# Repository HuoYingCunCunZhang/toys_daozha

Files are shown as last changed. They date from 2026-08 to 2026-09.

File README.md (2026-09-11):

# 道闸玩具（toys_daozha）

道闸（barrier gate）造型的儿童玩具。**语音是核心**：ESP32-S3 + ESP-SR 离线识别，只认三条命令——起杆 / 落杆 / 复位。配一个 ESP-NOW 直连的三键遥控器。目标玩家 6~10 岁。

---

## 当前进度（2026-09-11）

| 阶段 | 状态 |
|---|---|
| 需求冻结 | ✅ |
| 电路方案 | ✅ |
| 原理图连线 + 网表校验 | ✅ **24 条网络全通**（删了 `M_FAULT`）|
| 元器件选型与实测尺寸 | ✅ 全部转 📄 |
| 改 EDA 封装（4 项 + U1 行距） | ✅ **全部完成** |
| **PCB 布局** | ✅ **已定稿并校验**（22 元件 / 119 焊盘 / 0 重叠 / 占用率 51%）|
| **PCB 布线** | ✅ **完成，DRC 零错误**（105 段 / 0 过孔 / 两面 GND 覆铜）|
| **CAD 结构件** | ✅ **v3.3**——12 个零件，闸杆改 +Y，STL/3MF 全部导出 |
| 装配手册 + 采购/紧固件清单 | ✅ 已对齐 v3.3，含 9 颗贴片件的手焊步骤 |
| **固件 · 骨架** | ✅ **主机 + 遥控器工程已建**，见 [`firmware/`](firmware/README.md) |
| **固件 · 主机实机** | ✅ **按键长按走/松手停 实测通过**（09-11）。控制模型已换：限位只做"碰到就停"，无回零、无 T 标定、无防砸 |
| **固件 · 遥控器实机** | 🔴 **三个键没按就全读 0**，疑轻触开关脚对与封装不符，待万用表量（见 firmware/README） |
| **固件 · 语音（M5）** | ✅ **已实现**（ESP-SR：WakeNet9「你好小智」+ MultiNet7 中文三词），识别率待实测 |
| 遥控器 · BOM 与尺寸 | ✅ 定案（无状态灯 / 无电量检测 / 外壳可放大）|
| 遥控器 · 原理图 | ✅ **已建工程并连线，8 条网络几何校验全通过**（含 2 条阳性对照）|
| 遥控器 · PCB | ✅ **完成，DRC 零错误**（板 **57×33**，8 条网络分层连通已验证）|
| 遥控器 · 外壳 | ✅ **完成**（**63 × 40 × 26**）——上盖只留抬杆/落杆两个按键孔，加四条板压条 |

> 🔴 **板子和底座已放大**：承载底板 100×55 → **120 × 65**，底座 163×63×25 → **183 × 73 × 25**。
> 原因：U4 实测 **37mm** 长（当初定 100×55 时按 SX1308 的 23mm 算），37mm 连续跨度在小板上差 3.2mm 放不下。
> 放大后占用率 71% → **51%**，最小间距 ≥0.87mm。坐标见 [机械约束 §七之二](道闸玩具_底板机械约束_v1.md)。
>
> 🔴 **U1 DevKit 封装的排针行距是错的，已修正**：系统库给 22.86mm，卖家尺寸图是 **25.4mm**。照原样打样 DevKit 插不进去。
>
> 🔴 **闸体从 x=25 挪到了 x=55**（CAD 解冻时发现）：PCB 定稿的起杆按键在 x=+20，而闸体原来占 x=2…48，**整颗按键被闸体盖住**。按"结构让路给 PCB"挪的是闸体。

---

## 文档索引（按使用顺序）

| # | 文档 | 作用 |
|---|---|---|
| 1 | [需求规格说明书 v2](道闸玩具_需求规格说明书_v2.md) | 要做什么、不做什么 |
| 2 | [电路与结构设计方案 v2.5](道闸玩具_电路与结构设计方案_v2.md) | 总体方案、GPIO 分配、状态机 |
| 3 | **[元器件尺寸基准 v1](道闸玩具_元器件尺寸基准_v1.md)** | **所有物理尺寸的唯一事实源。CAD 和 PCB 都只能引用它** |
| 4 | [底板网表基准 v2](道闸玩具_底板网表基准_v2.md) | 25 条网络的连接关系、防砸方案 |
| 5 | [底板选型锁定 v1](道闸玩具_底板选型锁定_v1.md) | 器件型号与 EDA device uuid |
| 6 | **[底板机械约束 v2](道闸玩具_底板机械约束_v1.md)** | **PCB 布局必读**：外形、安装孔、净空、钉死的器件位置、要改的封装 |
| 7 | **[采购与装配清单 v1](道闸玩具_采购与装配清单_v1.md)** | **买什么、谁来焊、按什么顺序装**（新手向）|
| 8 | [紧固件清单 v1](道闸玩具_紧固件清单_v1.md) | 27 颗螺丝的规格与长度依据 |
| 9 | [cad/README](cad/README.md) | CAD 源码说明、建模踩过的坑 |
| 10 | **[firmware/README](firmware/README.md)** | **固件工程说明**：环境、编译烧录、引脚、状态机、上电前必查的三件事 |

---

## 下一步该做什么（给接手的 agent）

### 任务 1 · 改 EDA 封装 ✅ **已完成**

见 [机械约束 §七](道闸玩具_底板机械约束_v1.md)、[选型锁定 §已执行](道闸玩具_底板选型锁定_v1.md)。

1. ✅ **SW3** → 已换 SK-12D07VG7（LCSC C49284740），脚距 **2.0**、总跨 8.3，实测确认
2. ✅ **U2 DRV8833** → 已换自建 2×8 封装，排距 **15.24**。**焊盘编号是按列的，布线前先看[焊盘对照表](道闸玩具_底板选型锁定_v1.md)**
3. ✅ **U4 MT3608** → 已换自建四角焊盘封装，孔距实测 **30 × 7**，孔 φ1.651，模块外形 **37×17**（正极同边已确认）
4. ✅ **删除 N12（M_FAULT）和 R6** —— GPIO38 已释放为空闲

**U2 / U4 是自建器件，存在个人库**（不在系统库），uuid 见选型锁定文档。

> EDA 可以用 `easyeda-api` skill 直接操作，桥接环境已跑通。
> ⚠ 原理图导线的 `getState_Net()` **现在全部返回空**，网表只能靠坐标几何重建，**且校验工具必须带阳性对照**。方法见[选型锁定 §校验方法变了](道闸玩具_底板选型锁定_v1.md)。
> 改前的原理图完整快照存在 `_sch_backup_before_footprint_change.json`。

### 任务 2 · PCB 布局布线

✅ **布局已定稿**：板 **120 × 65**（x −88…+32，y ±32.5），−X 两角切 5×5，4 个安装孔在 (−82,±27)(+26,±27)。
22 个元件坐标全部在 [机械约束 §七之二](道闸玩具_底板机械约束_v1.md)，那是**唯一事实源**。

> ⚠ **原则**：**结构让路给 PCB**。安装孔、按键、卧式开关的位置都可以为布线让路，最后按 PCB 定稿反推结构——不是 PCB 迁就已开好的结构孔。

✅ **布线也已完成**：105 段、0 过孔、两面 GND 覆铜、**DRC 零错误**。详见 [机械约束 §七之三](道闸玩具_底板机械约束_v1.md)。

> ⚠ **接线注意**：J2 的限位端子已对调 —— **第 2 脚 = 落杆限位，第 3 脚 = 起杆限位**。

### 任务 3 · 解冻 CAD ✅ **已完成（v3.0）**

12 项积压改动全部执行，清单和依据见 [cad/README](cad/README.md)。要点：

- 底座 **183×73×25**、承载底板 **120×65**，元件位置全部按 PCB 定稿坐标
- **转毂拆成 `hub` + `cam`**（一整件穿不过 φ8.5 壁孔）；壁孔内侧加 φ12×4 凸台，轴承长度 2→6mm
- 凸轮升程 **3.3** + 两端 18° 过渡斜坡；开关托板拆成**两块安装台** + 径向长圆孔
- **新增打印件**：`cam`、`btn_cap` ×2 —— 共 **12 个零件**
- 计划外抓到一条：**闸体正压在起杆按键上**，闸体从 x=25 挪到 55

自检 43 条用例全过（含 16 条阳性对照），11 个可导出件全部 `Volumes=2 / Simple=yes`。

```powershell
cd D:\cad; .\run_check.ps1
```

### 任务 4 · 遥控器电路 ✅（原理图 / PCB / 外壳全完成）

**流程与主机一致**：定 BOM 与尺寸 → 原理图 + 网表校验 → 封装 → PCB → **反推外壳**。
唯一不同：主机的底座能随便放大，而遥控器 60×30×20 是**手持尺寸**，所以"塞不塞得下"提前算了，
不等画完 PCB 才发现（见[遥控器网表基准](道闸玩具_遥控器网表基准_v1.md)）。

已完成：

- **三条拍板**：无状态灯、无电量检测、外壳尺寸可动
- **原理图已建并校验**：工程 `道闸玩具遥控器`，8 条网络逐条对上基准，两条阳性对照通过
- 按键落 **GPIO4/3/1**（避开 strapping 脚 GPIO2，且全在深睡唤醒可用的 GPIO0~5 内）
- 拨动开关**串在电池与 C3 之间** —— 顺带堵死了"插 USB 烧录时 5V 倒灌进电池"

PCB 也已完成（**57 × 33**，DRC 零错误）。当初写在[网表基准 §5](道闸玩具_遥控器网表基准_v1.md)的两条硬要求都已兑现：
① **C3 的天线端悬出板边**（底下压铜会削弱 ESP-NOW 距离）；
② **U1 两排焊盘间距已核**（主机就栽在 DevKit 封装行距 22.86 vs 实际 25.4）。

✅ **外壳也已反推完成：63 × 40 × 26**（不是当初估的 68×32×22）。三个方向都是被锁死算出来的，
上盖只留抬杆/落杆两个按键孔（复位走主机语音），四条板压条把板子压住而不只是托住。

### 任务 5 · 固件 ✅（骨架 + 语音都已落地）

**工程在 [`firmware/`](firmware/README.md)**，两个独立 ESP-IDF 工程共用 `common/gate_proto.h`：

- `firmware/gate/` —— ESP32-S3。状态机、PWM 20kHz、限位、按键、蜂鸣器、ESP-NOW 收 + 配对
- `firmware/remote/` —— ESP32-C3。按键唤醒 → 发一条 → 深睡
- **M1~M5 的逻辑都写完了**。语音是两段式：喊 **"你好小智"** 唤醒（蜂鸣器短鸣应答），
  再说 **起杆 / 落杆 / 复位**。命令词用拼音在 `sr.c` 里运行时注册，改词不用重训模型

> 🔴 **第一次上电必须先确认三件事**（`MOTOR_INVERT` 是猜的、限位 NC/NO 极性、**USB 和拨动开关要同时开**），
> 三条都写在 [firmware/README](firmware/README.md#-第一次上电必须先确认的三件事)。别跳过。

> 🔴 **改了 `sdkconfig.defaults` 一定要删掉 `sdkconfig` 再编** —— defaults 只在
> sdkconfig 缺这一项时才生效，否则改了等于没改。语音的模型选择全在 defaults 里。

### 任务 6 · 上电联调（进行中）

**已过**：PSRAM/240MHz/模型加载 ✅、限位接线 ✅、电机方向 ✅（用户自验）、
底座按键长按走/松手停/5s 上限 ✅、语音模型加载 ✅（麦克风还没接）。

**卡着**：遥控器三个键没按就全读 0（见 firmware/README 遥控器待查）。

**控制模型已经改了两次**（09-10 删回零，09-11 换成长按走/松手停），
原因都是"限位开关装不到精确位置"。原来那套 T 标定/防砸/超时/缓停已全部作废，
以后开关装准了再考虑加回来。下面这段是历史，保留作参考：

#### 旧 · 上电自检顺序（M1 → M2 → M3）

**PCB 元器件已全部焊完（2026-09-02）**，代码侧没有已知欠账了，卡的是实测。顺序不能乱：

1. **只插 USB，先不接电机**。开机看日志：PSRAM 认到 8MB、
   `sr: 唤醒词模型 …` 这行有没有出来（没出来 = 模型没烧进 `model` 分区）
2. **确认限位极性**：两个限位同时读到"到位"是物理上不可能的，固件会直接 FAULT。
   真买到 NO 型就把 `board.h` 的 `LIMIT_ACTIVE_LEVEL` 改 `0`
3. **接电机，USB 插着 + 拨动开关打开**（电机的 VM 只来自升压，光 USB 不转），
   按抬杆键看方向。反了就 `MOTOR_INVERT` 改 `1` 重烧 —— **这个值现在是猜的**
4. **标定 T**：让它从一个限位干净地跑到另一个限位几次，日志里的 `T=` 会收敛
5. 最后才是接电池 + 升压联调（M6/M7）

三条铁律见 [firmware/README](firmware/README.md#-第一次上电必须先确认的三件事)。

---

## 还没定的（不阻塞，但要记着）

| 项 | 说明 |
|---|---|
| ~~TP4056 两颗 LED 的确切位置~~ | ✅ **已按实物定为 (−80, 0)**（原 (−84,−6) 是猜的，作废）。观察窗 10×6，`LED_WIN_POS` 已改 |
| 遥控器灯孔/开关孔具体位置 | 等遥控器 PCB 布局。CAD 里已按合理假设留好（`RC_PSW_*` / `RC_LED_POS`），定稿后回来核对 |
| ~~DevKit 排针行距~~ | ✅ **已确认 25.4 是行距、27.94 是板宽**。系统库封装错成 22.86，已自建修正版 |
| 触点材质 | 限位开关用于 µA 级信号，建议问卖家确认镀金还是银 |
| 打印公差 | `GAP`(0.25) 和按键帽的 `CAP_CLR`(0.5) 要按自己的打印机调。按键帽建议树脂打、`CAP_CLR` 调到 0.3 |

---

## 关键约束（改任何东西前先看这几条）

1. **转轴离地 42mm、杆顶 46mm** —— 用户小车最矮 50mm，必须低于它。CAD 里 `PIV_Z = PIVOT_ABS − BASE_H` 自动保持，**别直接改 `PIV_Z`**
2. **排母只买低背 5.0mm** —— 常见的 8.5mm 装不下
3. **限位开关必须带簧片杠杆** —— 无杠杆直动式行程 0.3mm，会被 3.3mm 的凸轮升程压毁
4. **防砸是行程超时，不是电流检测** —— 延迟 0.2~1.6s、压紧力约 1.3N。成品 DRV8833 模块不引出 AISEN，电流检测做不了
5. **先定元件再改 CAD** —— 本项目 v2.2~v2.6 连续修的硬伤，根因都是拿没核实的尺寸建模
6. **换了事实源就要回头扫一遍引用它的注释** —— 按键位置从"结构挑"改成"PCB 定"之后，参数区里那条"按键 x<2，因为闸体占 2…48"就没人看了，结果闸体正压在按键上。**跨零件的约束，单看任何一个零件都是正常的**，必须把两件摆到装配位置求交才看得见（`cad/check.scad` 的 `t=53/54` 就是这条的回归测试）
7. **凸轮顶丝是转毂唯一的轴向固定** —— 松了闸杆一拉就把转毂拔出来。装配时点螺纹胶

---

## 工具环境

- **OpenSCAD** 装在 `F:\Program Files\OpenSCAD\openscad.exe`（不在 PATH）
- **OpenSCAD 在中文路径下无法渲染** → CAD 工作副本放 `D:\cad\`，改完再同步回 `cad\`
- 命令行用数字选择器 `-D p=N`，别用 `-D part="x"`（PowerShell 会吞引号）
- 嘉立创EDA 桥接已跑通，见 `easyeda-api` skill

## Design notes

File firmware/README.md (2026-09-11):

# 道闸玩具 · 固件

两个独立 ESP-IDF 工程，共用 `common/gate_proto.h` 里的 ESP-NOW 包定义。

| 目录 | 芯片 | 干什么 |
|---|---|---|
| `gate/` | ESP32-S3-DevKitC-1 **N16R8** | 状态机、电机、限位、按键、蜂鸣器、ESP-NOW 收、**语音（ESP-SR）** |
| `remote/` | ESP32-C3 SuperMini | 按键唤醒 → 发一条 ESP-NOW → 接着深睡 |
| `common/` | — | 12 字节 `gate_pkt_t`、CRC16、命令码。**改这里两边一起改** |

方案依据：[`../道闸玩具_电路与结构设计方案_v2.md`](../道闸玩具_电路与结构设计方案_v2.md) §4 引脚 / §7 固件。
引脚的唯一事实源是[底板网表基准](../道闸玩具_底板网表基准_v2.md) §3，代码里不许自定义引脚。

---

## 环境

本机装的是 **ESP-IDF v6.1-beta1**（用 eim 装的，不是 v5.4）：

| | |
|---|---|
| 框架 | `D:\esp\v6.1-beta1\esp-idf` |
| 工具 | `D:\Espressif\tools` |
| 激活脚本 | `C:\Espressif\tools\Microsoft.v6.1-beta1.PowerShell_profile.ps1` |

```powershell
& "C:\Espressif\tools\Microsoft.v6.1-beta1.PowerShell_profile.ps1"
```

> ⚠ **v6 的组件名和 v5.x 不一样**，`main/CMakeLists.txt` 的 `REQUIRES` 是按 v6 写的：
> `driver` 元组件被拆散，gpio/ledc 要点名 **`esp_driver_gpio` / `esp_driver_ledc`**。
> 退回 v5.x 的话这里要改回 `driver`。
> （另一条与版本无关：**没有叫 `esp_now` 的组件**，`esp_now.h` 一直在 `esp_wifi` 里。）

## 编译烧录

```powershell
cd D:\workspace_zc\toys_daozha\firmware\gate
idf.py set-target esp32s3      # 只在第一次、或换芯片时跑
idf.py build
idf.py -p COM# flash monitor    # 退出 monitor 是 Ctrl+]
```

遥控器同理，`set-target esp32c3`，目录换 `firmware\remote`。

> `set-target` 会先跑 `fullclean`，而它拒绝清理"不像 CMake 构建目录"的残留 —— 上一次
> configure 失败留下的半成品 `build\` 就属于这种。手工 `rm -rf build` 再来。

**当前编译状态**：主机 ✅ / 遥控器 ✅，都是 `-Wall -Wextra -Werror` 零警告。
`daozha_gate.bin` **2.29MB**（加了 ESP-SR 之后从 788KB 涨上来的，4MB app 分区还剩 45%）、
`srmodels.bin` **2.90MB**（烧到 0x810000 的 `model` 分区，6MB 够）、
`daozha_remote.bin` ≈798KB。

> ⚠ **C3 没有 RTC IO**（`SOC_RTCIO_PIN_COUNT == 0`）—— `rtc_gpio_*` 那套函数在这颗芯片上
> 根本不存在，不用也不能手工去开 RTC 上拉。深睡期间的上拉由
> `ESP_SLEEP_GPIO_ENABLE_INTERNAL_RESISTORS`（默认开，已确认 sdkconfig 里是 `y`）
> 在 `esp_deep_sleep_start()` 里按唤醒模式自动配。
> 深睡唤醒 API 在 v6 也改名了：`esp_deep_sleep_enable_gpio_wakeup` →
> **`esp_sleep_enable_gpio_wakeup_on_hp_periph_powerdown`**。

> 🔴 **烧遥控器之前先把拨动开关拨到关。**
> C3 板上 Type-C 的 5V 直通 5V 脚，开关不关的话 USB 的 5V 会顺着 5V 脚倒灌回
> TP4056 的 OUT+（OUT+ 与 B+ 直连，保护只切负极）= 拿 5V 怼电池。

---

## 引脚（抄自网表，别在这里改）

### 主机 ESP32-S3

| 功能 | 脚 | 网络 | 电气 |
|---|---|---|---|
| 电机 AIN1 / AIN2 | 9 / 10 | N9 / N10 | LEDC PWM 20kHz，11 bit |
| 电机 nSLEEP | 11 | N11 | 高=工作。模块内部下拉 → 上电默认休眠 |
| 限位·抬到位 90° | 12 | N16 | 内部上拉 + **NC 接法**：未压合读 0，到位读 1 |
| 限位·落到位 0° | 13 | N17 | 同上。断线读 1（=到位）→ 停机，失效方向安全 |
| 按键·抬杆 / 落杆 | 17 / 18 | N18 / N19 | 按下接 GND，内部上拉 |
| 蜂鸣器 | 2 | N23 | → R5 → Q1(S8050) → LS1，高=响 |
| 电池采样 | 1 | N15 | ADC1_CH0，12dB 衰减，100k/100k 分压 |
| 麦克风 SCK/WS/SD | 4 / 5 / 6 | N20~N22 | INMP441，I2S0 标准模式，16kHz/32bit/单声道 |

> ⚠ **接线**：J2 第 **2** 脚接**落杆**限位、第 **3** 脚接**起杆**限位 —— PCB 布线时把
> 原理图上这两个端口对调过（[机械约束 §七之三](../道闸玩具_底板机械约束_v1.md)），GPIO 侧不受影响。

### 遥控器 ESP32-C3

| 功能 | 脚 | 备注 |
|---|---|---|
| 抬杆 / 落杆 / 复位 | 4 / 3 / 1 | 必须在 GPIO0~5（只有这些支持深睡唤醒），且避开 strapping 脚 GPIO2 |

复位键焊在板上但**上盖是实心面板、按不到**（2026-08-15 拍板：三个键对 6~10 岁太容易误触）。
固件仍然处理它，拆壳调试时可用。

> 🔴 **遥控器待查（2026-09-11）**：C3 插在遥控器板上、USB 供电，三个键**没按就全读 0**：
> ```
> rc: 键电平 抬(GPIO4)=0 落(GPIO3)=0 复位(GPIO1)=0，0=按下
> ```
> 后果是遥控器一醒就以为抬+落都按着 → 等 3s 发配对 → 等松手 8s 超时 → 睡 → 立刻又醒，
> **每 11.4s 循环发一次配对广播**（主机日志里 `已配对` 每 11.4s 一条就是这个）。
> 电池插没插无关（按键接的 N5 GND 就是 C3 自己的 GND）。
> 三个一起错 = 同一个错误复制三次，最大嫌疑是**轻触开关内部相通的脚对与封装假设不符**
> （网表基准 §86 按"1/3 相通、2/4 相通、1-2 跨开关"画的；实物若是 1/2 相通，1-2 就永远短路）。
> **下一步**：C3 拔掉，万用表通断档量每颗开关四脚两两之间**不按**时哪对通 ——
> 信号和 GND 必须跨在**不相通**的两脚之间。

---

## 交互

| 操作 | 结果 |
|---|---|
| 底座单键**按住** | 往那个方向转；**松手就停** |
| 底座双键同时按住 3s | 复位 / 急停 |
| 遥控器单键**按住** | 同上（按住每 100ms 发一个 JOG 保活包，松手发 STOP） |
| 遥控器抬+落同时按住 3s | 发配对广播（**主机必须在开机后 60s 内**） |
| 喊"你好小智" → 再说"起杆/落杆" | 语音没法"按住"，改为**定时走** `TIMED_TRAVEL_MS`（2200ms） |
| 喊"你好小智" → "复位" | 急停 + 清故障 |

### 🔴 控制模型：长按走、松手停（2026-09-11）

限位开关装不到精确位置（凸轮相位 / 开关安装台都难调准），所以**它不再是动作的依据**。
走多远由操作的人盯着，固件只兜底：

| 谁在兜 | 触发 | 值 |
|---|---|---|
| 限位开关 | 动作中开关**从没压到变成压到** → 停，两声 | 只认边沿。起步时已压着的不认，所以开关卡住/断线/没接都**不阻止启动** |
| 看门狗 | `JOG_DEADMAN_MS` 没收到"还按着" → 停 | 300ms。底座键 50ms 投一次、遥控 100ms 发一次，容忍连丢 2 包 |
| 按住上限 | 按满 `JOG_MAX_MS` → 强制停，急促三声 | 5s。抬杆侧有机械止挡，按住 = 堵转发热。**松手再按才能继续** |
| 定时走 | 语音命令走满 `TIMED_TRAVEL_MS` → 停 | 2200ms（初值取自 09-10 那轮标定收敛的 T=2243） |

**三个输入源共用一套机制**：谁持续喂 JOG 谁就在控制，喂断了就停。遥控器掉线、走出范围、没电，
杆子都不会一直转 —— 这一条是遥控器能做"长按"的前提，不能省。

**有意放弃的**：T 标定、1.15T 防砸、1.5T 超时、0.85T 缓停、开机自检。
它们全都以"有可靠限位"为前提，没有这个前提就没有参照物。以后开关装准了可以再加回来。

**配对窗口只有开机后 60s**，否则邻居家一按遥控器就能把主机抢走。配对成功蜂鸣器升调两声。

蜂鸣（毫秒序列见 `buzzer.c` 的 `SEQ_*`）：

| 场景 | 节奏 |
|---|---|
| 收到命令 / 唤醒应答 | 一短声 40ms |
| 到位 | 两声 60-80-60 |
| 防砸反转 | 急促三声 |
| **故障** | **响 400ms、停 300ms，无限循环**（听起来是"嘀..嘀..嘀.."，不是一条长音）|
| 配对成功 | 升调两声 |

**故障鸣叫只有复位或断电能停。** 最常见的触发是**限位没接**：两个限位 GPIO 内部上拉、
悬空都读 1 = 两个都"到位"，0° 和 90° 不可能同时成立 → 上电自检判定接线错，
拒绝转电机。接上 J2 就自己好了。
**唤醒应答借用"一短声"** —— 整机没喇叭，这是唯一能告诉小孩"我在听"的通道。

---

## 状态机

```
IDLE ──JOG_UP / CMD_OPEN──► UP ──限位边沿 / 看门狗 / 按满 5s / 定时走完──► IDLE
IDLE ──JOG_DN / CMD_CLOSE─► DOWN ──同上──► IDLE
任意态 ──复位──► IDLE（急停）
FAULT：现在没有自动触发源，留着给语音"复位"当急停用
```

没有回零、没有已知位置。**固件不知道杆在哪，也不需要知道** —— 每条命令都是
"往这个方向走，直到有人让它停"。

---

## 语音（M5，`sr.c`）

```
INMP441 --I2S0--> feed_task --> AFE --> detect_task --> MultiNet7 中文 --> evt_post(SRC_VOICE)

实测 AFE 流水线（上电日志里 print_pipeline 打的）：
[input] -> |VAD(WebRTC)| -> |WakeNet(wn9_nihaoxiaozhi_tts)| -> [output]
```

单麦 + `AFE_TYPE_SR` 就是这个形态：AEC/SE 用不上（无喇叭、无阵列），
**非线性降噪本来就不在 SR 通路里**（`esp_afe_config.h` 对 `AFE_TYPE_SR` 的注释写死了）。
别照着"AFE 应该有 NS/AGC"去改配置，那是 VC（语音通话）通路的形态。

**两段式**：先喊唤醒词，再说命令。唤醒词用乐鑫现成模型（自定义唤醒词是付费商业服务，
方案 §7.4），当前选的是 **你好小智**（`CONFIG_SR_WN_WN9_NIHAOXIAOZHI_TTS`）。
命令词是 **MultiNet7 中文**，**在 `sr.c` 里用拼音运行时注册**，改词不用重训模型：

| id | 拼音（任一句都算） | 事件 |
|---|---|---|
| 1 | `qi gan` / `tai gan` / `kai men` | `EVT_CMD_OPEN` |
| 2 | `luo gan` / `jiang gan` / `guan men` | `EVT_CMD_CLOSE` |
| 3 | `fu wei` | `EVT_CMD_RESET` |

唤醒后 5.76s 内没听到命令词就自动退回等唤醒；这几秒里 **WakeNet 是关掉的**
（省算力，也免得命令词里的音再触发一次唤醒）。

### 配置在哪

模型的选择全在 `gate/sdkconfig.defaults`，**不是在代码里**：

```
CONFIG_MODEL_IN_FLASH=y                  # 模型进 flash 的 model 分区
CONFIG_SR_WN_WN9_NIHAOXIAOZHI_TTS=y      # 唤醒词（多选菜单，勾几个烧几个）
CONFIG_SR_MN_CN_MULTINET7_QUANT=y        # 命令词模型
CONFIG_ESP_DEFAULT_CPU_FREQ_MHZ_240=y    # ESP-SR 要 240MHz，160 会掉帧
CONFIG_ESP32S3_INSTRUCTION_CACHE_32KB=y
CONFIG_ESP32S3_DATA_CACHE_64KB=y
CONFIG_ESP32S3_DATA_CACHE_LINE_64B=y
```

> ⚠ **改了 `sdkconfig.defaults` 必须删掉 `sdkconfig` 再编**。defaults 只在
> `sdkconfig` 里没有这一项时才生效，改 defaults 而不删 sdkconfig = 什么都没发生。

> ⚠ **分区名必须叫 `model`** —— esp-sr 的 CMake 写死了去查这个名字的分区，
> 查不到就只是打条消息、不生成也不烧 `srmodels.bin`，固件跑起来才报"没模型"。

模型占用：`mn7_cn` 2.6MB + `wn9_nihaoxiaozhi_tts` 0.3MB ≈ **2.9MB**，6MB 分区够。

### 首次上电实测（2026-09-02，COM7 / 只插 DevKit）

全部符合预期，逐条对上了：

```
esp_psram: Found 8MB PSRAM device          # 八线 PSRAM 认到
cpu_start: cpu freq: 240000000 Hz          # ESP-SR 要的 240MHz 生效
boot:  4 model  Unknown data  01 82 00810000 00600000   # model 分区 6MB
MODEL_LOADER: Successfully load srmodels
sr: 唤醒词模型 wn9_nihaoxiaozhi_tts（你好小智），命令词模型 mn7_cn
AFE: AFE Pipeline: [input] -> |VAD(WebRTC)| -> |WakeNet(wn9_nihaoxiaozhi_tts,)| -> [output]
7 active speech commands:  qi gan / tai gan / kai men / luo gan / jiang gan / guan men / fu wei
motor: PWM 20000 Hz / 11 bit, MOTOR_INVERT=0
E motion: FAULT: 两个限位同时到位，检查 J2 接线与 NC/NO
comms: 主机 MAC b8:1f:3f:c3:ba:b0，信道 1，配对窗口 60s
```

- **那条 FAULT 是对的**：限位没接 + 内部上拉 = 两个都读 1 = 两个都"到位"，
  这是物理上不可能的组合，固件按设计拒绝转电机。接上限位后应该自己消失
- **`VBAT ≈ 3.87V` 这时候没有意义**：GPIO1 悬空，读的是浮空噪声，不是电池
- **主机 MAC `b8:1f:3f:c3:ba:b0`** —— 遥控器配对时对这个

### 上电后先看这两行日志

```
sr: 唤醒词模型 wn9_nihaoxiaozhi_tts（你好小智），命令词模型 mn7_cn
sr: 唤醒（音量 -33.2 dBFS），请说命令
```

**`data_volume` 就是调麦克风增益的依据**：常态说话应落在 **−45 ~ −25 dBFS**。
偏小就把 `sr.c` 的 `MIC_GAIN_SHIFT` 调小（每 −1 增益翻倍），削顶就调大。
INMP441 是 24bit MSB 对齐塞在 32bit 槽里，`>>16` 才是数学上正确的 int16，
现在取 **14**（多给 4× 增益），超量程做饱和截断而不是回绕。

### 三个容易踩的点

- **L/R 接的是 GND**（网表 N8）→ 数据在**左**声道，`slot_mask = I2S_STD_SLOT_LEFT`。
  接反了读到的是一片 0，AFE 不报错，只是永远唤不醒
- **槽宽必须 32bit**：INMP441 一帧要 64 个 BCLK，按 16bit 配根本收不到数
- **不要把 `cfg->wakenet_model_name` 改成 `models` 里的指针**：那个字段是
  `afe_config_init` 自己 strdup 的，`afe_config_free` 会去 free 它 ——
  塞进模型表的指针进去，等于把模型表里的字符串给释放了

### 任务与核

`sr_feed` / `sr_detect` / AFE 内部任务全部**优先级 5、钉在 core 1**（方案 §7.2 的"独占一核"），
core 0 留给 WiFi/ESP-NOW。语音跟其它输入一样只 `evt_post()`，不碰电机。

---

## 代码里两个不显眼的坑

- **限位模块叫 `endstop.h` 不叫 `limits.h`** —— `main/` 在 include path 上，
  叫 `limits.h` 会盖掉 C 标准库的 `<limits.h>`，报错点会离现场很远。
- **只有 `motion.c` 能调 `motor_*`**（方案 §7.2 的规矩）。其它任务一律 `evt_post()`，
  否则语音和遥控会抢电机。

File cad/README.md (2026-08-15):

# 道闸玩具 v3.0 · 结构件 CAD

> ## ✅ 已解冻并改完（2026-08-14）
> v2.6 冻结时积压的 12 项改动**全部执行完毕**，另外抓出并修掉一处冻结期间新长出来的硬伤（闸体压住按键，见下）。
> 参数化源码：`daozha.scad`（OpenSCAD 2021.01 验证通过）。所有尺寸集中在文件顶部参数区，改一处全局联动。

- 元件尺寸唯一事实源：[`../道闸玩具_元器件尺寸基准_v1.md`](../道闸玩具_元器件尺寸基准_v1.md)
- PCB 定稿坐标（结构必须跟随它）：[`../道闸玩具_底板机械约束_v1.md`](../道闸玩具_底板机械约束_v1.md) §七之二
- 紧固件规格：[`../道闸玩具_紧固件清单_v1.md`](../道闸玩具_紧固件清单_v1.md)
- 装配流程：[`../道闸玩具_采购与装配清单_v1.md`](../道闸玩具_采购与装配清单_v1.md)

---

## v3.0 改了什么

### 🔴 计划外的一条：闸体原来正压在起杆按键上

PCB 定稿把两个按键放到 **(0, +20) 和 (+20, +20)**，而闸体占 **x = 2…48** —— x=20 那颗按键整个被闸体盖住，手指根本够不到。

v2.6 的参数区里其实写着「按键 x < 2，因为闸体占 2…48」，但**按键位置后来改由 PCB 定**，没人回头看那条注释。这类"约束写在被约束的一方，改动发生在另一方"的失配，布尔自检抓不到——两者根本不在同一个零件里，求交永远是空的。

按项目原则（**结构让路给 PCB**）只能挪闸体：`HS_X_ABS` **25 → 55**，闸体改占 x = 32…78，离按键边缘 7.75mm。顺带也更像真道闸——底座放大到 183 之后，闸体待在 x=25 会把 +X 侧空出 43mm。

> **代价**：上盖走线孔跟着挪到电池上方（55, −16.5）。闸体下来的飞线要贴着电池顶面（有 10mm 空隙）往 −X 走到板子上。电池自己的引线也是朝 −X，同一条通道。

### 计划内的 12 项

| # | 改了什么 | 依据 / 要点 |
|---|---|---|
| 1 | 底座 150×55×22 → **183×73×25**；承载底板 87×47 → **120×65** | 根因是 U4 实测 37mm，老板子放不下。`BASE_L=板长+63`、`BASE_W=板宽+8` |
| 2 | 电池仓按**成品** 51×34×10 重排（不是裸电芯 50），仓 53.5 长，引线朝 −X | 卖家确认含保护板和引线 |
| 3 | **转毂拆成 `hub` + `cam`** | 一整件穿不过 φ8.5 壁孔，见下 |
| 4 | 壁孔内侧加 **φ12 × 4 凸台**，轴承长度 2 → **6mm** | 壁只有 2mm，而闸杆是从壁外悬伸的 |
| 5 | 电机 `MOT_L` 25.2、`SHAFT_L` **10**、`SHAFT_FLAT` **2.45**，末端锪坑让开 φ4×0.7 轴根凸台 | 全部换成实测值。轴长 9→10 后孔深自动跟随，否则轴顶死 |
| 6 | 凸轮升程 **3.3**（φ18.6），凸起两端各加 **18° 过渡斜坡** | 升程由官方规格书 **PT Max 3.0** 反推，不是卖家表的"行程 2.2"。原来是直上直下的台阶，直杆压柄只会顶死 |
| 7 | 开关托板整块方板 → **两块独立安装台**；底孔改**径向长圆孔**（±1.5 可调）、深 4.5 不打穿 | `SW_HOLE_R` 12.5→**14.6**、`SW_SPACING` 9.5→**6.5** |
| 8 | 按键孔 φ6.5 → **φ9** + 背面 φ12.5 沉孔（总深 4.0）+ φ14 导向凸台；**新增 `btn_cap` ×2** | 顶杆够不到盖面（差 7.4mm），且 φ3 裸顶杆小孩按着硌手。⚠ 法兰厚只能取 3.0，见下 |
| 9 | 麦克风：前面板内侧 **φ15.4 × 1.2 圆窝 + 上下两片压舌** | 圆板 φ14×1，零螺丝零胶 |
| 10 | 上盖开 TP4056 充电灯观察窗；Type-C 开口对准 y=−6、拨柄开口对准 y=+17 | 全部按 PCB 实际坐标 |
| 11 | 遥控器补**拨柄开口** + **板载蓝灯观察孔**；电池仓按含保护板 **7×21×32** | 开口位置**暂定**，等遥控器 PCB |
| 12 | 文件头版本号归位 | 闸杆自攻底孔 v2.3 就统一到 `BOSS_PILOT` 了 |

### 按键帽的法兰厚度是被"按不按得动"卡住的

帽子能下压的距离 = **沉孔总深 4.0 − 法兰厚**，而按下去要走 **0.2**（预留浮动，免得静止时就预压住开关）+ **0.25**（开关行程）= **0.45mm**。

法兰取 3.5 就只剩 0.5mm 可压，余量 **0.05mm** —— 打印公差 ±0.15 就能让法兰先坐死在沉孔底上，**开关根本压不到**。所以取 **3.0**，余量 0.55mm；导向也不受影响（法兰 3.0 + 柄在通孔里 1.5，跨距仍有 4.5mm）。

> 这类"**两个尺寸之差**决定功能"的地方，单看任何一个数字都很正常，布尔自检也测不出来（帽子确实坐得进、确实拔不出）。只能靠把行程链算一遍。

### 转毂为什么必须拆

| | |
|---|---|
| 左壳 −Y 壁上的轴颈孔 | **φ8.5** |
| 夹杆臂（壁外） | 36 × 14 |
| 凸轮（壁内） | φ18.6 |

两端都远大于 φ8.5，而分模面在 y=0、这道壁整个属于左壳，**拆开左右壳也分不开它**。

**拆凸轮而不是拆臂**：凸轮几乎不受力（只拨开关），闸杆弯矩和电机扭矩全部走主体这一整件。

新方案的固定链：

- **角度**靠 `cam` 的 D 形孔配轴颈上的**键面**定死 —— 不靠装配时把顶丝拧到某个角度去猜时序
- **轴向**靠几何夹：往 −Y 拔 → 凸轮撞轴承凸台；往 +Y 推 → 夹杆臂撞外壁（只有 1mm 行程）
- **顶丝**只负责把凸轮锁在轴颈上。它长在凸起的**背面**，全程扫 −X/−Z 那个空象限，永远碰不到开关
- 顶丝是径向的，从分模面伸手够不着 → **闸体前面板上开了一个 φ3 进入孔**，闸杆放到落杆位时顶丝正对它，长柄小螺丝刀直接捅进去拧

---

## 自检怎么跑

```powershell
.\run_check.ps1
```

`check.scad` 是布尔交集自检，`run_check.ps1` 把 **59 条用例**跑一遍并与期望值比对（主机 43 + 遥控器 16；跑满一轮约 30 分钟，`t=16` / `t=44` 那种多角度扫掠最慢）。

**期望表就在 `run_check.ps1` 里，改用例记得同步。里面 24 条是阳性对照（必须非空）——别删。** 没有阳性对照的自检失效了也不会报警，v2.2 就是这么栽的。

> **阳性对照要覆盖"东西根本不存在"这种情况。** `t=17/18` 验了开关底孔"没打穿外壁"和"是通的"，可是**整块安装台不存在时这两条照样过**——没有料，求交当然是空的。所以另加了 `t=55/56` 验孔四周有料，而且**两块安装台必须分开验**：合在一个用例里，只要有一块在就非空了。

单跑一条：`.\run_check.ps1 -Only 40`

### 新增的关键用例：装配路径

```
t=40  转毂上要穿过 φ8.5 壁孔的那一段, 减掉壁孔通道后必须什么都不剩   -> EMPTY
t=41  阳性对照: 把凸轮装回去(= v2.6 的一整件)后同样的判定必须非空   -> NON-EMPTY
```

这条专治「静态求交测不出装配路径」那个盲区：`t=16` 早就验过转毂在最终位置不干涉闸体，但**一整件根本走不到那个位置**。

### 新增的关键用例：跨零件失配

```
t=53  按键帽 vs 闸体                              -> EMPTY
t=54  阳性对照: 闸体放回 x=25 必须压住按键帽       -> NON-EMPTY
```

就是上面那条硬伤的回归测试。**这类问题只有把两个零件摆到装配位置去求交才看得见**——单看任何一个零件都完全正常。

### ⚠ 写用例的铁律：不许留共面接触

两个实体面贴面求交，CGAL 给的是**零体积薄片**，导出 STL 有几百个三角形，看文件大小会被判成"非空"。v3.0 第一轮就这么冒出 5 条假失败：

| 假失败 | 真相 |
|---|---|
| 托盘 vs 上盖 | 交集 bbox `z[22.00..22.00]` —— 就是贴合面本身 |
| 遥控下壳 vs 上壳 | `z[17.00..17.00]` |
| 电芯 vs 托盘 | `x[36.00..36.00]` —— 电芯 −X 面贴着挡边 |
| 转毂穿壁孔判定 | `z[11.00..11.00]` —— 判定用的半空间正好切在夹持段顶面 |
| 闸杆底孔探针 | 这条是**真的**：拿 φ2.0 探针去探 φ1.7 自攻底孔，当然探不通 |

处置：凡"应该刚好贴上"的地方一律错开 0.01~0.05 再求交；探自攻底孔用 `PROBE_S`(1.4)，探 M2 过孔才用 `PROBE`(2.0)。
原 `t=1` / `t=2`（上下壳直接求交）已删除，作用被 `t=13` / `t=14`（抬 0.01）完全覆盖。

> 判定"空/非空"是看导出 STL 的大小。所以一个零体积薄片会被误判 —— 这就是上面那条铁律的由来。

### 遥控器那 16 条又踩了同样的坑两次

- **`t=60` 板 vs 下壳**：第一版拿一块**没有螺柱缺口**的方板去求交，撞的是我自己画错的测试模型，不是设计缺陷。**测试模型必须和真件同形**。
- **同一条又漏了 Z 向贴合面**：只在 XY 缩了 0.05，交集出来是 `z[7.10..7.10]` 的零厚度薄片 —— 那是板本来就该坐在螺柱承托肩上的贴合面。**缩要三个方向一起缩。**
- **`t=71` 阳性对照本身是失效的**：原来拿 12mm 高的开关当"必须撞上盖"的对照，可板面 8.7 + 12 = 20.7 根本够不到 23 的盖背面 —— **这个对照永远会过，等于没设**。改成 16mm 才成立。
  > 阳性对照也要验算，不能想当然。一个永远通过的对照比没有对照更危险，因为它给人"我有对照"的错觉。

### 自检还没覆盖的（知道就好，别以为全过就万事大吉）

| 没测的 | 现在靠什么保证 |
|---|---|
| **止口环下方那圈的净高**（14.4mm）| `t=22` 只测中央区。环下方靠[机械约束 §三](../道闸玩具_底板机械约束_v1.md)那张叠高表手算——最高的是 U2 的 12.5，余 1.9mm。要自动化的话得拿 `layout()` 里的元件块去和上盖求交 |
| **元件实际外形** | `layout()` 里都是长方块近似，不是真封装 |
| **打印公差** | 全部按名义尺寸建模。`GAP` / `CAP_CLR` 要按自己的机器调 |
| **受力** | 纯几何，没有任何强度校核 |

---

## 看爆炸图

```powershell
& "F:\Program Files\OpenSCAD\openscad.exe" -D p=13 -o png\explode.png --imgsize=1500,1300 --camera=60,-45,105,64,0,22,720 daozha.scad
```

GUI 里把文件头的 `part` 改成 `"explode"` 也一样。出图见 [`png/explode.png`](png/explode.png)。

原理是**同一个 `assembly()` 出两种图**，靠 `EXP` 系数撑开：

| EXP | 结果 |
|---|---|
| 0 | 装配态（`p=0`）|
| 1 | 完全炸开（`p=13`）|
| 0~1 之间 | 半程，见 [`png/explode_half.png`](png/explode_half.png) |

所以做**装配动画**只要扫这个值：

```powershell
0..20 | ForEach-Object { $v = $_ / 20.0
  & "F:\Program Files\OpenSCAD\openscad.exe" -D p=0 -D "EXP=$v" -o "png\anim_$('{0:d2}' -f $_).png" --imgsize=900,780 --camera=60,-45,105,64,0,22,720 daozha.scad }
```

（`-D` 赋的值会覆盖文件里的定义，所以 `-D EXP=0.45` 能压过 `p` 推出来的那个 0/1。）

**炸开方向不是随便挑的，一律取零件真实的装配方向**，这样爆炸图同时就是装配顺序图：

| 零件 | 方向 | 为什么 |
|---|---|---|
| 承载底板 / 上盖 / 按键帽 | +Z | 自下而上叠 |
| 闸体左右壳 | ∓Y | 沿分模面掰开 |
| 凸轮 → 转毂 | −Y（凸轮近、转毂远）| 沿转轴轴向抽出。**顺序就是拆的顺序**：先退凸轮才能拔转毂 |
| 闸杆两段 | +X | 顺着插槽方向拔 |
| 电池 | −Y | 从仓里侧向取出 |

每个零件还画一条**引导线**，从它的装配位置连到炸开位置（`GUIDE = false` 可关掉）。
`ex(位移, 锚点)` 的第二个参数就是画线用的锚点，新加零件时补上即可。

> 电池、承载底板和板上元件（DevKit / TP4056 / 升压 / 端子 / 按键…）现在也进了 `assembly()`，
> 所以爆炸图能直接当装配示意图看。它们都是**长方块近似**，不是真封装。

## 导出 STL

```powershell
.\export_stl.ps1
```

单件导出（用数字选择器，避开 PowerShell 传引号的坑）：

```powershell
& "F:\Program Files\OpenSCAD\openscad.exe" -D p=6 -o stl\hub.stl daozha.scad
```

`p` 取值：1=layout 2=base_tray 3=base_top 4=house_l 5=house_r 6=hub 7=bar_a 8=bar_b 9=rc_bottom 10=rc_top **11=cam 12=btn_cap 13=explode**，`p=0` 用文件里的 `part` 字符串（默认 assembly）。

> ⚠️ **路径不能有中文**。OpenSCAD 在中文路径下无法渲染，工作副本放 `D:\cad`，改完同步回 `cad\`。

## 遥控器（v3.1，按 PCB 定稿反推）

**外壳 63 × 40 × 26**，全部尺寸都是被算出来的，不是挑的：

| 方向 | 被什么锁死 |
|---|---|
| 长 63 | **双向锁死**：−X 端拨柄尖在 x=−32.5，外壁面必须落在 −31.5 才露得出来；+X 端 USB 插头壳长只有 6.5mm。内腔加长任何一边都会失效 |
| 宽 40 | 板 33 宽 + 两侧让位。板本身为了给螺柱腾缺口，已经往 −Y 加宽 3mm 做了条纯安装边 |
| 高 26 | 地板 2 + 电池 **4.6** + 支撑 0.5 + 板 1.6 + U1 叠高 **11.7** + 上盖 3 |

**坐标系有两套**：PCB 用它自己的原点（板 x ±28.5、y −18…+15），外壳是对称 rbox，差一个 `RC_PCB_DY = 1.5` 的 Y 偏移。凡是"对准板上某器件"的特征一律写 PCB 坐标再加偏移，**别直接填外壳坐标**。

### 两条是自检抓出来的，不是算出来的

1. **外壳高度只能是 26，不能是 24**。24 时上盖背面在 21，而按键帽的 φ11 导向凸台往下伸 2mm 到 19 —— 而 U1 叠高顶面在 20.4，**凸台正撞在模块上**。凸台位置由 PCB 的按键坐标定死（SW3 在 x=20，压在 U1 正上方），挪不了。（`t=64`）
2. **U1 必须插低背排母**（要反复拔下来改程序），叠高 6.7 → 11.7。

### ❌ 不开第二个 Type-C

充电器插错到 C3 那个口时，5V 会经 5V 脚 → 拨动开关 → TP4056 的 OUT+，而 OUT+ 与 B+ 直连（保护只切负极）= 直接怼电池。开发板烧不了，但那是靠 DW01 救命。**改成拆壳拔模块烧录。**

## 零件清单（13 件）

| 文件 | 零件 | 尺寸 (mm) | 材料/颜色 | 打印要点 |
|---|---|---|---|---|
| `base_tray` | 底座下托盘 | 183 × 73 × 22 | PLA 深灰 | 开口朝上平放，无支撑 |
| `base_top` | 底座上盖板 | 183 × 73 × 5.5 | PLA 深灰 | 平放，止口朝上 |
| `house_l` | 闸体左壳（轴孔/轴承凸台/两块开关安装台/麦克风窝/止挡筋） | 46 × 30 × 62 | PLA 黄 | 剖面贴板 |
| `house_r` | 闸体右壳 | 46 × 23 × 62 | PLA 黄 | 剖面贴板 |
| `hub` | 转毂主体（臂 + 轴颈 + 电机 D 孔 + 配重仓） | 36 × 14 × 23.5 | **树脂或 PETG** | 唯一受力件，100% 填充 |
| `cam` | **凸轮盘（新增）** | 20.3 × 18.6 × 5 | 树脂或 PETG | 顶丝锁在 hub 轴颈上 |
| `btn_cap` | **按键帽 ×2（新增）** | φ12 × 13.2 | **树脂**（间隙做 0.3） | 立着打，露出盖面 5mm |
| `bar_a` | 闸杆根段（含 20mm 插榫） | 170 × 5 × 8 | PLA 白 | 平放 + brim |
| `bar_b` | 闸杆末段 | 150 × 5 × 8 | PLA 白 | 平放 + brim |
| `rc_bottom` | 遥控器下壳 | **63 × 40 × 23** | PLA 深灰 | 开口朝上 |
| `rc_top` | 遥控器上壳 | **63 × 40 × 5** | PLA 深灰 | 平放 |
| `rc_btn_cap` | **遥控器按键帽 ×3（新增）** | φ9 × 12.1 | **树脂** | 立着打 |

最长零件 **183mm**（底座），220mm 幅面的家用打印机可直接打。

**几何校验**：11 个可导出件全部 `Volumes = 2` / `Simple = yes`（单一封闭实体、无游离体、无封闭空腔、2-manifold 合法）。

## 打印参数

- 层高 0.16mm（闸杆、转毂、凸轮、按键帽）/ 0.2mm（外壳）
- 壁 3 圈（闸杆壁只有 1.2mm，靠外圈保证强度）
- 填充 20%（外壳）/ 100%（转毂、凸轮）
- 闸杆**不要**加支撑，中空腔是设计好的；根段两端已开 φ2 排料孔
- 按键帽下柄做成了锥形（φ8 → φ12），就是为了不出现 2mm 的水平悬空，别改成直柱

## 装配顺序

**完整六阶段流程见 [采购与装配清单 §5](../道闸玩具_采购与装配清单_v1.md)**。CAD 这边只强调三条：

1. **按键帽必须在扣上盖之前从背面放进沉孔**（法兰 φ12 比通孔 φ9 大，从正面塞不进去）
2. **转毂从壁外插进去、凸轮从腔内套上**，然后从前面板的 φ3 孔拧顶丝。顺序反了装不上
3. **限位开关先松着拧**，通电试到"凸起刚好压下、基圆刚好释放"再拧紧长圆孔

## 内部排布

以 [底板机械约束 §七之二](../道闸玩具_底板机械约束_v1.md) 为准。`layout` 视图（`-D p=1`）里的元件**全部按 PCB 定稿坐标摆**，不是示意位置。

## 建模时踩过的坑（改参数时注意）

1. **内腔挖空高度必须是 `HS_H - 2*WALL`**，写成 `HS_H` 会把顶盖捅穿。
2. **带孔的螺柱不能在挖完内腔后 union 上去**——union 会把底孔在底板那 2mm 里重新填实，孔变成上下封死的盲腔。正确顺序是：先 (壳体 − 内腔)，再并实体特征，**最后统一开孔**。v3.0 的轴颈孔就是因此挪到最后开的：它要一次穿透 −Y 壁**和后加的轴承凸台**，留在原地会被凸台重新填实。
3. **不要让特征"刚好相切"**到底板/顶盖。相切接触产生非流形边（`Simple: no`）。所有接合都要真实互穿 ≥1mm。
4. **底座内部特征必须写在 `difference()` 之外**，否则会被内腔一起减掉。
5. **盖板背面的 2mm 止口是隐形杀手**（v2.3 的 1、2 两条都栽在它上面）。改任何与盖板相关的尺寸时问自己两句：孔打穿它了吗？下壳的螺柱给它让位了吗？现在这两处都统一走 `LIP_T` 参数，别再写死 2。
6. **沉头孔翻转 180° 时，`csk()` 的 `h` 必须是"到沉窝所在面"的完整厚度**，不是面板厚度。
7. **转毂的局部坐标不等于装配坐标**：装配时 `rotate([-90,0,0])`，映射是 局部 Y → 装配 −Z、局部 Z → 装配 +Y。凡是给转毂加特征，先把这条映射写在注释里再动手。
8. **左右对开壳的对拧螺柱必须两边都有**：一边出螺纹柱，另一边出同径导向柱撑到分模面。
9. **`rbox` 是实心的**。用它做"止口"会得到一整块板而不是一圈边，把内腔净高整个吃掉 2mm——而且这块板在渲染图里几乎看不出来。想做"环/框"记得再挖一次中央。
10. **内腔净高是分区的**：中央区（`|x|<LIP_IN_X` 且 `|y|<LIP_IN_Y`）到 z=`TRAY_H`，止口环下方只到 `TRAY_H−LIP_T`。当前是 22 / 20。给元件排位置前先确认它在哪个区。
11. **别把尺寸链写死**。`PIV_Z` 原来硬编码 22，其实是"转轴离地 42 − 底座高"的结果；一旦调底座高度就会悄悄违反锁定的转轴高度。现在写成 `PIVOT_ABS - BASE_H`，约束才真的被表达出来。v3.0 底座从 22 加到 25，`PIV_Z` 自动从 20 变 17，转轴离地仍是 42。
12. **转动件的限位不能靠"把挡块摆到那个角度"**。挡块必须待在转动件的**扫掠包络之外**，包络由"侧面到转轴的距离"决定而不是角度。用**扫掠差集**让几何自己算出挡块该在哪。
13. **做扫掠并集要对相邻位置取 `hull()`**。只把离散角度的实例并起来，在"角度覆盖变窄"的半径上会漏出细缝，差集之后变成提前挡路的毛刺。实测 5° 步长的漏缝让闸杆 85° 就撞上。
14. **D 形孔是 圆 ∩ 半空间，不是 圆 ∪ 方槽**。写成并集的话孔比轴还大，D 面完全没起作用，轴插进去空转——渲染图上还挺像那么回事。自检里用"整根圆柱必须插不进去"当阳性对照（`t=31`）。
15. **N20 机身是 10×12 方形，不是圆的**。按圆柱建模的话对角线 15.6mm 根本塞不进去。
16. **（v3.0 新）约束注释要写在会被改动的那一方**。"按键 x<2 因为闸体占 2..48"写在按键参数旁边，但真正会变的是按键位置的来源（PCB）和闸体位置，结果两边都改了、注释没人看。这类跨零件的失配布尔自检抓不到——两者不在同一个零件里，求交永远是空的。
17. **（v3.0 新）自检用例里不许留共面接触**，会出零体积薄片被误判成"非空"。详见上面自检那节。
18. **（v3.0 新）探针直径要配孔的类型**。φ2.0 探 M2 过孔（φ2.4）合适，探自攻底孔（φ1.7）永远探不通——那是探针选错了，不是零件有毛病。

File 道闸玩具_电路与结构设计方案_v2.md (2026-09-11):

# 道闸玩具 · 电路与结构设计方案 v2.5

> ⚠️ **物理尺寸以 [元器件尺寸基准 v1](道闸玩具_元器件尺寸基准_v1.md) 为准。**
> 本文档中的元件尺寸只作方案说明，与基准表冲突时以基准表为准。
> ⚠️ **坐标约定**：本文档沿用旧约定（**Y=高度、Z=车行方向**），而 CAD 与基准表用 **Z=高度、Y=车行方向**。读本文时请把 Y↔Z 对调。

> 依据：`道闸玩具_需求规格说明书_v2.md`
> v2.0 → v2.1 变更：闸杆改从**按键相反侧**伸出、起杆角度 80°→**90°**、转轴高度 76→**42mm**、底座按键 3→**2** 个、Type-C 移到**前端面**、**取消爆闪灯/天窗**、**取消 VL53L0X**（改堵转检测防砸）

---

## 1. 系统总览

```
┌──────────────────────────┐            ┌──────────────────────────────────────────┐
│  遥控器 60×30×20          │            │  道闸主机                                  │
│  ESP32-C3 SuperMini      │  ESP-NOW   │  ┌── 闸体 46×46×62（黄，纯净顶面）──────┐  │
│  · 抬杆 / 落杆 / 复位 三键 │◄─────────►│  │ N20 6V 15rpm + 转毂 + 双限位微动      │  │
│  · 板载 WS2812 状态灯     │  2.4G 直连 │  │ 90° 机械止挡筋 · 配重仓               │  │
│  · 502030 锂电 250mAh     │  固定信道1 │  │ INMP441 麦克风（前面板格栅）           │  │
│  · TP4056 Type-C          │            │  └──────────────────────────────────────┘  │
│  · 深度睡眠 <10µA         │            │  ┌── 底座 183×73×25 ────────────────────┐  │
└──────────────────────────┘            │  │ ESP32-S3-DevKitC-1 N16R8（平放）      │  │
                                        │  │ 承载底板 · DRV8833 · 升压              │  │
     ◄── -X 前（长脚）                    │  │ TP4056 · 103450 锂电 1800mAh          │  │
     按键×2 · Type-C · 总开关             │  │ 蜂鸣器                                │  │
                                        │  └──────────────────────────────────────┘  │
                                        └──────────────────────────────────────────┘
                     闸杆 300×5×8 从 +X 侧伸出，转轴离地 42mm，杆顶 46mm
```

**方向约定**：`-X` = 前（长脚，放按键和 Type-C）；`+X` = 闸杆伸出方向（道路侧）；`Z` = 车辆行驶方向。**闸杆与按键分处闸体两侧，杆不会扫过按键。**

---

## 2. 主机 BOM

| 类别 | 型号 | 数量 | 选型理由 / 注意事项 |
|---|---|---|---|
| 主控 | **ESP32-S3-DevKitC-1 N16R8** | 1 | ESP-SR 模型分区要 6MB，PSRAM 是 AFE 硬性要求。底座内**平放**（板长 63mm > 内高 17mm，不能立放） |
| 麦克风 | INMP441（I2S MEMS） | 1 | 装闸体前面板内侧。整机无喇叭 → **v1 §7.4 的自唤醒问题不存在** |
| 电机 | **N20 减速电机 6V 15rpm** | 1 | 经 5V 驱动 ≈12.5rpm，90° 行程约 1.4s，接近真实道闸节奏 |
| 电机驱动 | **DRV8833** 模块 | 1 | 过流/过热保护 + nSLEEP 待机断电 |
| ~~电流采样~~ | ~~0.33Ω 1W 电阻 + 10kΩ/100nF RC~~ | ~~1~~ | ❌ **已删除**。成品 DRV8833 模块不引出 `AISEN`，电机电流不经过 `GND` 脚，采样读不到有效信号。改用**行程超时反转**，见 [网表基准 v2 §4/§5.1](道闸玩具_底板网表基准_v2.md) |
| 限位开关 | 微动开关**（必须带簧片杠杆）** | 2 | **常闭 NC 接法**（fail-safe）。由转毂凸轮压杠杆。~~短柄无杠杆~~ **已推翻**：凸轮升程 3mm，直动柱塞总行程只有 ~0.5mm，会被压毁，见 [基准表 §1](道闸玩具_元器件尺寸基准_v1.md) |
| 按键 | 6×6×**12** 轻触开关（底座 3.5 + 柄 8.5）**+ 打印按键帽 ×2** | **2** | 抬杆 / 落杆。复位 = 双键同时长按 3 秒 / 语音 / 遥控器 |
| 总电源 | SS12D00 拨动开关 | 1 | 底座前端面，串电池正极 |
| 蜂鸣器 | 有源蜂鸣器 3.3V，φ9×5mm | 1 | 取消爆闪灯后**唯一的反馈通道** |
| 电池 | **103450 锂聚合物 2000mAh**（50×34×10mm，34g，带保护板） | 1 | 18650 带座 21mm，底座内高只有 17mm 装不下。**带保护板的实际总长待实测**，可能超过电池仓的 52mm，见基准表 §3 |
| 充电 | **TP4056 Type-C 模块（带 DW01+FS8205 保护）** | 1 | 必须带保护板。**Rprog 换 2kΩ → ≈580mA**（0.32C），小空间发热可控，满充约 3.5h |
| 升压 | 5V 升压模块（SX1308 / MT3608） | 1 | 输出调 **5.1~5.2V**。去掉喇叭后峰值负载只剩 ~0.6A |
| 电容 | 470µF/10V 低 ESR ×1、220µF ×1、100nF ×3 | | 见 §3 |
| 其他 | 1N5819 ×1、100kΩ ×2、M2 自攻 ×12 | | 电源隔离 + 电池采样 |
| 机械件 | φ8 铜套 ×1、M2 顶丝 ×1、M5 钢螺母 ×2（配重，可选） | | |

**遥控器 BOM（2026-08-15 定案）**：

| 器件 | 数量 | 说明 |
|---|---|---|
| ESP32-C3 SuperMini | 1 | 22.52 × 18，**焊针向下** |
| 6×6 轻触开关 | 3 | 抬杆 / 落杆 / 复位。**高度待定**——要按内腔算完才知道要不要配按键帽（主机就栽在这儿）|
| **SK12D07VG7 拨动开关** | 1 | 🔴 **不是 SS12D00**。开关孔开在端面，需要**卧式侧拨**；SS12D00 是立式拨柄朝上，方向对不上。这个坑主机已经踩过一次 |
| TP4056 Type-C 模块（带保护）| 1 | **28 × 17**（不是 26），必须带 DW01+FS8205 |
| 502030 锂电 250mAh | 1 | 含保护板按 **7 × 21 × 32** 留仓 |

**没有的东西（2026-08-15 用户拍板）**：

- ❌ **无状态灯**。原方案的"板载 WS2812（GPIO8）"取消 —— 顺带解决了一处文档打架：本文写 WS2812、基准表写普通蓝色 LED，两者驱动方式完全不同。现在都不用管了，**上盖也不开灯孔**
- ❌ **无电量检测**。原方案 GPIO0 挂 100k/100k 分压，静态就要 **18.5µA**，而深睡指标是 <20µA —— 光分压吃掉全部预算，而遥控器只有 250mAh。取消后 BOM 里一颗电阻都不需要。没电了就是按键没反应，拨到关、插上充电即可

> ⚠ 遥控器**还没有原理图和 PCB**，选型锁定只覆盖底座承载底板。
>
> ⚠ **主机没有任何指示灯**——BOM 里一颗 LED 都没有，结构上也没有灯孔，TP4056 自带的充电灯被埋在底座里看不见。方案见基准表 §5。

### 相对 v1 的删除清单

| 删除 | 原因 |
|---|---|
| MAX98357A + 4Ω3W 喇叭 | 不做语音播报。**连带消除 v1 §7.4 的声学隔离难题** |
| 18650 + 电池座 | 20mm 高的底座装不下 |
| 红外对射管 | 对射需两侧立柱，与"装在底座"矛盾 |
| WS2812 闸杆灯带 | 灯带 10mm 宽，闸杆只有 5mm |
| **WS2812 爆闪灯 ×2 + 天窗 + 半透光片** | 用户取消 |
| **VL53L0X ×2 + 防砸使能开关** | 用户可选取消。见下方说明 |
| 第三个底座按键（复位） | 用户改为 2 键 |
| AMS1117 备用 LDO | 去喇叭后 DevKit 板载 LDO 余量充足 |

### 为什么不用侧装测距（原"堵转检测"论证已部分失效）

不是省钱的问题——VL53L0X 约 ¥9/只，两只才 ¥18。真正的原因是**覆盖范围**：传感器装在底座侧面，25° 视场角在 250mm 处只覆盖约 110mm 宽的锥形区，而闸杆有 **300mm** 长，杆中段和末端下方是盲区。而行程超时测的是"闸杆有没有按时到位"，同样**覆盖闸杆全长、没有盲区**——只是响应从毫秒级变成秒级（0.2~1.6s，压紧力约 1.3N）。

代价是失去"来车自动抬杆"（需要非接触检测）。GPIO 7/8/15/16 已预留，随时可以加回。

---

## 3. 电源链路

```
103450 LiPo 1800mAh (3.0~4.2V)
  │
  ├─► TP4056 + DW01/FS8205 保护  ◄── Type-C（底座前端面）
  ├─► 总电源拨动开关（底座前端面）
  ├─► 100kΩ ─┬─ 100kΩ ─ GND  → GPIO1 (ADC1_CH0) 电池采样，并 100nF
  │
  └─► 升压 5.1V ─┬─► 470µF + 100nF ─► DRV8833 VM
                  │                    DRV8833 GND ─► GND   (采样电阻已删除)
                  └─► 1N5819 ─► 220µF ─► DevKit 5V ─► 板载 LDO ─► 3.3V ─► INMP441 / 逻辑
```

v1 §4 的三重防护（大电容 / 二极管隔离 / PWM 软启动）全部保留。峰值负载从 v1 的 ~1.6A 降到 ~0.6A，电容可从 1000µF 降到 470µF。

### 功耗与续航

| 工况 | 电流 @3.3V |
|---|---|
| ESP32-S3 常态跑 ESP-SR（AFE+WakeNet+MultiNet） | ~110mA |
| 蜂鸣器（瞬时） | ~30mA |
| 电机峰值（瞬时 @5V） | ~400mA |
| **待机监听合计（折算到电池侧）** | **~115mA** |

1800mAh ÷ 115mA ≈ **15.6 小时连续监听**（取消 ToF 和爆闪灯后比 v2.0 提升约 30%）。

---

## 4. 引脚分配

**ESP32-S3-DevKitC-1 N16R8 禁用脚**：GPIO26~32（Flash）、GPIO33~37（八线 PSRAM）、GPIO19/20（USB）、GPIO43/44（UART0）、GPIO0/3/45/46（strapping）。

### 4.1 主机

| 功能 | 引脚 | 备注 |
|---|---|---|
| 麦克风 SCK | GPIO4 | INMP441，I2S0 |
| 麦克风 WS | GPIO5 | |
| 麦克风 SD | GPIO6 | L/R 脚接 GND |
| ~~电机电流采样~~ | ~~GPIO7~~ | ❌ 已删除，**GPIO7 空闲预留** |
| 电机 AIN1 | GPIO9 | LEDC PWM 20kHz |
| 电机 AIN2 | GPIO10 | LEDC PWM 20kHz |
| 电机 nSLEEP | GPIO11 | 高=工作，低=待机断电 |
| 限位·抬到位（90°） | GPIO12 | 内部上拉，NC 接法 |
| 限位·落到位（0°） | GPIO13 | 内部上拉，NC 接法 |
| 按键·抬杆 | GPIO17 | 到 GND，内部上拉 |
| 按键·落杆 | GPIO18 | 双键同时长按 3s = 复位 |
| 蜂鸣器 | GPIO2 | |
| 电池采样 | GPIO1 | ADC1_CH0，11dB 衰减 |
| 预留（可加回 ToF） | GPIO8/14/15/16/21/47 | I2C + XSHUT ×2 + 灯 |
| 备用 | GPIO38~42, 48 | |

### 4.2 遥控器（ESP32-C3 SuperMini）

| 功能 | 引脚 | 备注 |
|---|---|---|
| 按键·抬杆 | **GPIO4**（U1 脚 13）| 三个键都必须落在 **GPIO0~5**：C3 的深睡唤醒只有这几个脚支持 |
| 按键·落杆 | **GPIO3**（U1 脚 12）| |
| 按键·复位 | **GPIO1**（U1 脚 10）| 原定 GPIO5，但它在符号左侧，接线要绕过整个芯片 |
| ~~状态灯~~ | — | ❌ 取消（无状态灯）|
| ~~电池采样~~ | — | ❌ 取消（无电量检测）|

三个键统一**按下接 GND**，用 C3 内部上拉，不需要外部电阻。

> 🔴 **为什么不用 GPIO2**：
> **GPIO2 是 ESP32-C3 的 strapping 脚，上电瞬间必须为高。** 按键按下是拉低的，
> 小孩按着"抬杆"键去拨电源开关，芯片就可能进不了正常启动模式。
> 而唤醒又限死在 GPIO0~5，可用的就 6 个，避开 GPIO2 之后正好剩 GPIO0/1/3/4/5。
> **这类问题做出来之后才发现就要重打板，画原理图之前定掉最省事。**
>
> ⚠ 这段原来写"取 3/4/5 三个连号"，**已作废**：连原理图时 GPIO5 在符号左侧，
> 走线要绕过整个芯片并与电源交叉，最终换成 GPIO1。**以上面的表格为准（4/3/1）。**

#### 遥控器供电拓扑（2026-08-15 定）

```
502030 电池 ──► TP4056 的 B+/B−（充电与保护，Type-C 在这块模块上）
                    │
              OUT+/OUT−
                    │
              SK12D07VG7 拨动开关（只断正极）
                    │
              C3 SuperMini 的 5V 脚 ──► 板载 LDO ──► 3V3
```

进 **5V 脚**而不是 3V3 脚：让板载 LDO 去稳压。电池 4.2→3.0V 掉到 LDO 压差以下之后输出就跟着电池走，而 C3 本来就能在 3.0V 工作，不影响。

**🔴 拨动开关必须串在电池和 C3 之间，不能串在别处** —— 这条同时解决了烧录时的倒灌问题：

C3 SuperMini 板上的 Type-C（烧录口）5V 是直通 5V 脚的。如果开关在别处、插着 USB 烧录时电池又接着，USB 的 5V 就会顺着 5V 脚倒灌回 TP4056 的 OUT+（而 OUT+ 与 B+ 是直连的，保护只切负极），等于**拿 5V 直接怼电池**。虽然 DW01 会在 4.28V 跳过充保护兜底，但这是靠保护电路救，不是设计。

开关串在中间以后：**关掉开关 = 电池与 C3 完全断开**，USB 5V 只能喂 C3 自己，倒灌路径不存在。

> **装配/开发规矩：烧录前先把拨动开关拨到关。** 充电不受影响 —— 充电走的是 TP4056 自己的 Type-C 到 B+/B−，跟开关无关。

**外壳只开 TP4056 那个 Type-C（充电口），C3 的烧录口留在壳内。** 理由：① 一个口对小孩更简单，不会插错；② 烧录要拆 4 颗螺丝，拆的时候自然会看到开关状态，杜绝倒灌；③ 固件出厂前烧好，之后基本不用再插。开发阶段嫌麻烦就先不装上盖。

---

## 5. 机械设计与核算

### 5.1 闸杆

- 截面 5(宽) × 8(高)，**空心，壁厚 1.2mm** → 截面积 25.4mm²
- 长 300mm，PLA 1.24g/cm³ → 质量 ≈ **9.4g**
- **分两段打印**：2×155mm，搭接榫 20mm + M2 螺丝 ×2，兼容 220mm 幅面打印机，也更耐摔
- **刚度**：I = 213mm⁴，自重悬臂端挠度 δ = wL⁴/8EI ≈ **0.58mm**，肉眼几乎看不出

### 5.2 扭矩

- 水平位最大静扭矩 = 9.4g × 15cm = **0.14 kgf·cm**
- N20 6V 15rpm 堵转约 2.5 kgf·cm，经 5V 驱动仍有 ~2.0 kgf·cm
- **安全系数 ≈14×**

### 5.3 90° 竖直位的两个新问题（v2.0 是 80°，不存在这些）

1. **过冲翻倒**：闸杆到 90° 时重力矩归零，若限位失效，惯性会带它越过竖直向后倒。
   → 闸体后侧设计**机械止挡筋**（在 **100°** 位置），微动限位是第一道、止挡筋是第二道保险。
   止挡块位置由**扫掠差集**算出（毛坯 − 转臂 0…100° 扫过的区域），不是手摆角度——手摆的话挡块会埋在转臂的扫掠包络里，闸杆 35~40° 就卡死。
2. **末端不减速就会撞止挡**：接近 90° 时重力不再帮忙减速。
   → 固件在行程 0.85T 之后把占空比降到 30%（比 v2.0 的 0.8T/40% 更早更低）。

### 5.4 配重

N20 减速箱不自锁，但 1:300 减速比下 0.14 kgf·cm 反射到电机端只有约 0.0005 kgf·cm，**减速箱摩擦足以驻停**，不会自己掉杆。

配重仓仍保留（转毂尾部，放 1-2 颗 M5 钢螺母，约 4-8g，力臂 22mm），用于让落杆更柔和。仓口 M2 螺丝封盖，**杜绝可脱落小件**。

### 5.5 倾覆核算

闸杆改为 +X 伸出后，150mm 底座的长脚在 -X 侧，正好**反向配平**：

- 倾覆力矩（绕底座后缘 X=+75）：9.4g × 100mm = **940 g·mm**
- 恢复力矩：底座塑料 45g×75 + 电池 35g×105 + 闸体总成 40g×50 ≈ **9050 g·mm**
- **安全系数 ≈9.6×**，稳定

### 5.6 转毂（一件三用）

一个 3D 打印件同时充当**轴套 + 凸轮 + 闸杆夹**，总长 22mm（CAD v2.3 重做过插槽，以 CAD 为准）：

| 段 | 尺寸 | 作用 |
|---|---|---|
| 内段 | φ16，长 11mm，**1 个**凸轮凸起 | 在闸体内压两个微动开关（两开关相隔 90°，单凸起随转毂转动依次压下；**2 个凸起是错的**，会在 0° 时同时压下两个） |
| 轴颈 | φ8，长 4mm | 穿闸体 Z=-23 侧壁的 φ8 铜套 |
| 外段 | 16×14×12 夹块，5×8 插槽 + M2 螺丝 | 夹闸杆根部 |
| 中心孔 | φ3 D 形，深 9mm + M2 顶丝 | 直接夹 N20 的 D 形输出轴 |

N20 输出轴伸出长度与 D 面对边尺寸**待实测**（本文原写 10mm，CAD 按 9mm 建、孔深 10.5mm）。电机端面距凸轮 0.5mm。**不需要额外传动轴、联轴器或齿轮。**

> D 形孔必须是 **圆 ∩ 半空间**（把圆切掉一块平面），不能写成『圆 ∪ 方槽』——那样孔比轴还大，D 面失效，轴会空转。

---

## 6. 结构参数表（可直接建模）

### 6.1 底座

> 🔴 **本表尺寸已全部过时**（2026-08-14）。底座经两次放大：150×55×22 → 163×63×25 → **183 × 73 × 25**，承载底板 **120 × 65**。
> 按键孔、Type-C 开孔等位置也全部改了。**唯一事实源：[机械约束 §七之二](道闸玩具_底板机械约束_v1.md)。** 下表仅供追溯当初的推导。

| 项 | 值（**已过时**） |
|---|---|
| 外形 | ~~150(X) × 55(Z) × 22(Y)~~ → **183 × 73 × 25** |
| 壁厚 / 底厚 / 顶板 | 2.0 / 2.0 / 2.0mm（不变）|
| 内腔 | ~~146 × 51 × 17~~ → **179 × 69 × 17**（高度未变）|
| 分件 | 下托盘 + 上盖板，M2 自攻 ×4 |
| 按键孔 | **φ9 ×2 + 背面 φ12.5×1.5 沉孔**，位置 ~~(−40,+10)/(−20,+10)~~ → **(0, +20) / (+20, +20)**（由 PCB 定）。配打印按键帽，按压面 φ8.5、露出盖面 5.0mm |
| Type-C 开孔 | **前端面 X=-75**，10×5mm，Y=8 |
| 总电源开关 | **前端面**，8×4mm，Z=+15。⚠ SS12D00G3 是拨柄朝上的立式开关，装底板上拨柄指天，与前端面开口**方向对不上**，见基准表 §1 |
| 压重仓 | X=-62 处 30×40×8 凹槽，M2 盖板 |

### 6.2 闸体

| 项 | 值 |
|---|---|
| 外形 | 46(X) × 46(Z) × 62(Y)，坐底座顶面 Y=22 → **顶面 Y=84，纯净无开孔** |
| X 位置 | X = +2 ~ +48 |
| 壁厚 | 2.0mm |
| 转轴中心 | X=+25，**Y=42**，轴线沿 Z，转毂从 **Z=-23** 侧壁伸出 |
| 闸杆姿态 | 落杆位：杆底 **Y=38**，杆顶 **Y=46**，沿 **+X** 伸出 |
| 起杆角度 | **90°**，凸轮限位 + **100° 机械止挡筋**（91° 离 90° 只差 1°，打印公差就能顶上；且止挡位置现由扫掠差集算出，不再手摆角度） |
| 麦克风格栅 | 前面板 X=+2，Y=60，φ1.8 ×4 通孔，背面留声腔。⚠ **CAD 里没有任何麦克风固定结构**，模块目前悬空，固定方式待拍板 |
| 分件 | 前壳 + 后壳，M2 自攻 ×4 |

### 6.3 闸杆

| 项 | 值 |
|---|---|
| 截面 | 5(Z) × 8(Y)，壁厚 1.2mm 空心 |
| 总长 | 300mm = 155 + 155，搭接 20mm |
| 分色 | 红/白交替，每段 37.5mm |
| 根部 | 20mm 实心，插入转毂夹块，M2 横穿 |

### 6.4 遥控器

| 项 | 值 |
|---|---|
| 外形 | 60(X) × 30(Z) × 20(Y)，四角 R4 |
| 内腔 | 56 × 26 × 16 |
| 按键 | φ6 ×3，顶面 X = -18 / 0 / +18 |
| Type-C | 一端面，10×5mm |
| 内部布置 | C3 SuperMini(22.5×18) 与 TP4056(26×17) 并排，电池 502030 垫底 |

---

## 7. 固件

### 7.1 状态机

```
上电 → UNKNOWN（位置不明，不动，等命令）
         │ 抬杆 ──► OPENING ──► OPEN(90°)
         │ 落杆 ──► CLOSING ──► CLOSED
      CLOSED ⇄ OPENING → OPEN(90°) ⇄ CLOSING → CLOSED
                                         ↓ 落杆超时
                                    立即反向 → OPENING（防砸）
任意态 ──故障──► FAULT（断电机、报警鸣叫、复位恢复）
复位入口：语音"复位" / 遥控器复位键 / 底座两键同时长按 3s
复位动作 = 清故障 + 回到 UNKNOWN，**不转电机**
```

> 🔴 **2026-09-11 再改：整个控制模型换成「长按走、松手停」。** 限位开关装不到精确位置，
> 不再是动作依据，只做"碰到就停"；走多远由人盯着。固件兜底三道：看门狗（300ms 没收到
> "还按着"就停）、按住上限（5s 强制停）、限位边沿。语音"起杆/落杆"改为定时走 2200ms。
> **T 标定 / 防砸 / 超时 / 缓停 全部作废** —— 它们以可靠限位为前提。详见 firmware/README。
>
> 🔴 **2026-09-10 改：删掉开机 HOMING。** 原设计上电自动慢速回零，实机暴露三个问题：
> ① 凸轮相位或开关位置差一点，就变成一开机 FAULT 长鸣、整机不可用；
> ② 拨开关瞬间杆子自己动，对 6~10 岁玩家是惊吓；
> ③ 回零是往落杆方向走，而**机械止挡只做在抬杆侧**，落杆侧一旦开关失效就只剩超时一道保护。
>
> 位置未知本来就不需要回零来消除 —— 每条命令都是「往这个方向走到限位为止」，不需要起点。
>
> **停止的三道闸门**：① 微动开关（NC 接法，断线读「到位」→ 停，失效方向安全）
> → ② 超时 `1.5×T` → ③ 机械止挡（**仅抬杆侧**）。
> 因为 ③ 在落杆侧缺席，②的超时值不能设宽。

### 7.2 FreeRTOS 任务

| 任务 | 优先级 | 职责 |
|---|---|---|
| `sr_task` | 5 | AFE + WakeNet + MultiNet，独占一核 |
| `motion_task` | 6 | 状态机、PWM、限位、**行程计时与超时判定** |
| `comms_task` | 4 | ESP-NOW 收发与配对 |
| `input_task` | 3 | 按键消抖、双键长按复位、电池采样、蜂鸣器 |

所有任务只往 `evt_queue` 投事件，**`motion_task` 是唯一能命令电机的地方**（保留 v1 的规则，避免语音和遥控抢电机）。

### 7.3 电机控制

- PWM 20kHz（低于此值电机啸叫刺耳）
- 软启动：占空比 40% → 目标值，200ms 线性斜升
- **末端缓停：0.85T 之后降到 30% 占空比**（比 v2.0 更早更低，因为 90° 位重力不再帮助减速）
- 到位刹车：AIN1=AIN2=高 保持 300ms，再拉低 nSLEEP 断电
- **防砸**：行程超时 —— 落杆超 1.15×T 未到位 → 反向 + 蜂鸣；超 1.5×T → FAULT 断电

### 7.4 语音（ESP-SR）

| ID | 拼音 | 动作 |
|---|---|---|
| 1 | `qi gan,tai gan,kai men` | 起杆到 90° |
| 2 | `luo gan,jiang gan,guan men` | 落杆 |
| 3 | `fu wei` | 复位 |

唤醒词用乐鑫现成的（自定义唤醒词是付费商业服务）。整机无喇叭，**不需要 v1 的 disable_wakenet 开关逻辑**。

### 7.5 Flash 分区（16MB）

| 分区 | 大小 | 内容 |
|---|---|---|
| nvs | 24KB | 配对 MAC、配置 |
| app | 4MB | 固件 |
| model | 6MB | WakeNet9 + MultiNet7 中文（无 esp-tts） |
| ota | 4MB | OTA 备份 |
| 其余 | ~2MB | 预留 |

### 7.6 ESP-NOW

沿用 v1 的 12 字节 `gate_pkt_t` 协议与配对流程，命令码收敛为 `CMD_OPEN=1 / CMD_CLOSE=2 / CMD_RESET=3 / CMD_PING=7`。双方固定信道 1，主机不连路由器。

---

## 8. 实施路线

| 阶段 | 目标 | 完成标志 |
|---|---|---|
| **M0** | 环境 | ESP-IDF 装好，S3 跑通 hello_world，PSRAM 识别 |
| **M1** | 电机 | **USB 供电**下控制 N20 正反转，触限位自动停 |
| **M2** | 状态机 | 2 按键完整走 落→抬(90°)→落，含软启动、缓停、超时、双键复位 |
| **M3** | 防砸 | 标定单程行程时间 T；手挡闸杆能在 1.15×T 触发反转（延迟 0.2~1.6s） |
| **M4** | 遥控器 | C3 → ESP-NOW → 主机响应；配对可用；深睡实测 <20µA |
| **M5** | 语音 | ESP-SR 跑通，3 条命令识别率可接受（**最难一步**） |
| **M6** | 结构 | 打印全部零件，装配，验证转毂/限位/90°止挡/闸杆刚度/倾覆 |
| **M7** | 电池装机 | 切到锂电，验证电机启动不复位；整机联调 |

**M1 铁律：必须用 USB 供电。** 电池+升压的电源问题和电机逻辑问题混在一起排查会非常痛苦。

---

## 9. 采购分批

- **第一批（M0~M3）**：ESP32-S3-DevKitC-1 N16R8、N20 6V 15rpm（顺便买个 30rpm 备选）、DRV8833 模块、微动开关 ×5、0.33Ω 1W 电阻 ×5、面包板+杜邦线
- **第二批（M4~M5）**：ESP32-C3 SuperMini ×2、INMP441、有源蜂鸣器
- **第三批（M6~M7）**：103450 锂电、502030 锂电、TP4056 Type-C 保护板 ×2、5V 升压模块、470µF/220µF、1N5819、拨动开关 ×2、φ8 铜套、M2 螺丝包
- **结构件**：嘉立创三维打印。闸体黄色，闸杆红白，底座深灰

---

## 参考

- [ESP-SR 命令词 MultiNet](https://docs.espressif.com/projects/esp-sr/en/latest/esp32s3/speech_command_recognition/README.html)
- [ESP-SR 唤醒词 WakeNet](https://docs.espressif.com/projects/esp-sr/en/latest/esp32s3/wake_word_engine/README.html)
- [esp-sr GitHub](https://github.com/espressif/esp-sr)

---

## 变更记录

| 版本 | 日期 | 说明 |
|---|---|---|
| v2.1 | 2026-08-10 | 依据需求书 v2.1 的完整方案 |
| v2.5 | 2026-08-12 | 按键定为 6×6×12（原写 5，差 8.4mm）；**新增打印按键帽 ×2** —— 加高底座后 12mm 顶杆仍差 1.4mm 够不到上盖，且 φ3.5 裸顶杆儿童按不舒服。按键帽按压面 φ8.5、**露出盖面 5.0mm**（用户指定，为保证儿童触感）；上盖孔 φ6.5→φ9 并加 φ12.5×1.5 背面沉孔做导向与防脱 |
| v2.4 | 2026-08-12 | 限位开关由"短柄无杠杆"更正为**必须带簧片杠杆**（凸轮升程 3mm vs 直动行程 0.5mm，量级不匹配） |
| v2.3 | 2026-08-12 | **同步网表 v2 的防砸方案变更**：删除电流采样电路（成品模块不引出 AISEN），改行程超时反转；GPIO7 释放为空闲 |
| v2.2 | 2026-08-12 | 与 CAD v2.6 对齐，修正 10 处不一致：凸轮凸起 2→1、止挡角度 91→100、底座高 20→22、内腔高 16→17、闸体顶面 82→84、转毂总长 24→22、内段 8→11mm；轻触开关高度与 N20 轴长标为待实测；补上拨动开关方向、麦克风无固定结构、遥控器缺开关孔/灯孔、主机无指示灯四处缺口。**物理尺寸的权威移交给《元器件尺寸基准 v1》。** |

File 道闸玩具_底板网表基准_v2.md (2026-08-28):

# 道闸玩具 · 模块承载底板 网表基准 v2

> 依据：`道闸玩具_电路与结构设计方案_v2.md`（v2.1）
> **用途**：画原理图/PCB 之前的"正确性基准"。画完后用 EDA API 读回实际网表，与本文件逐条比对。
> v1 → v2：**修正一个会导致防砸失效的错误**（详见 §5.1），改用行程超时防砸，删除电流采样电路。

---

## 1. 板子定位

**承载底板**：现成模块用排母插上，只有电源防护元件、按键、端子焊在板上。
~~外形受底座内腔限制：≤ 146 × 51 mm~~ → **反了：底座跟随板子。** 板子实际做到 **120 × 65**，底座随之变成 183 × 73 × 25。**元件高度 ≤ 16.4mm**（板面到上盖背面）。

---

## 2. 元件位号表

### 2.1 插接模块

| 位号 | 器件 | 连接 | 说明 |
|---|---|---|---|
| U1 | ESP32-S3-DevKitC-1 N16R8 | 2 × 1×22P 排母，行距 22.86mm | 主控，**平放** |
| U2 | DRV8833 双路电机驱动模块 | 排母（按实物） | 只用 A 通道 |
| U3 | TP4056 Type-C 充电模块（带 DW01+FS8205） | 1×4P | 见 §5.3 |
| U4 | 5V 升压模块 **SX1308 或 MT3608** | 1×4P | 二者等价，见 §5.4 |
| U5 | INMP441 I2S 麦克风模块 | 经 J3 引到闸体 | 装闸体前面板 |

### 2.2 板载分立元件

| 位号 | 值/型号 | 作用 |
|---|---|---|
| C1 | 470µF / 10V 低 ESR | DRV8833 VM 储能，**必须紧贴 VM 引脚** |
| C2 | 100nF | VM 高频去耦（手册要求 VM 至少 10µF 陶瓷，模块自带 + C1/C2 已满足） |
| C3 | 220µF / 10V | 主控 5V 侧储能，电机拉低总线时顶住 |
| C4 | 100nF | 主控 5V 去耦 |
| C5 | 100nF | 电池采样滤波 |
| D1 | 1N5819 肖特基 | 电源隔离，压降约 0.3V |
| R3 | 100kΩ | 电池分压上臂 |
| R4 | 100kΩ | 电池分压下臂 |
| R5 | 1kΩ | 蜂鸣器三极管基极限流 |
| R6 | 10kΩ | nFAULT 上拉（开漏输出必须外部上拉） |
| Q1 | S8050 NPN | 蜂鸣器驱动 |
| SW1 | 6×6×5 轻触 | 抬杆 |
| SW2 | 6×6×5 轻触 | 落杆 |
| SW3 | SS12D00 拨动 | 总电源 |

> v1 的 **R1(0.33Ω) / R2(10k) / C6(100nF) 已删除** —— 见 §5.1。

### 2.3 端子

| 位号 | 脚数 | 引到哪 |
|---|---|---|
| J1 | 2P | N20 电机 |
| J2 | 3P | 双限位微动开关（共 GND） |
| J3 | 6P | INMP441 麦克风（引到闸体） |
| J4 | 2P | 103450 锂电 |
| J5 | 2P | 有源蜂鸣器 |

---

## 3. 网表

### 3.1 电源

| # | 网络名 | 连接点 |
|---|---|---|
| N1 | `BAT+` | J4.1, U3.B+ |
| N2 | `BAT-` | J4.2, U3.B- |
| N3 | `VBAT_PROT` | U3.OUT+, SW3.1 |
| N4 | `VBAT_SW` | SW3.2, U4.IN+, R3.1 |
| N5 | `+5V` | U4.OUT+, C1.1, C2.1, D1.阳极, U2.VM |
| N6 | `5V_MCU` | D1.阴极, C3.1, C4.1, U1.5V |
| N7 | `3V3` | U1.3V3, U5.VDD, J5.1 ~~, R6.1~~（R6 已删）|
| N8 | `GND` | U3.OUT-, U4.IN-, U4.OUT-, **U2.GND**, U1.GND, U5.GND, U5.L/R, C1.2, C2.2, C3.2, C4.2, C5.2, R4.2, SW1.2, SW2.2, J2.1, Q1.E |

> ⚠️ **N2 与 N8 是两个独立网络**。带保护板的 TP4056，`B-` 与 `OUT-` 之间隔着 FS8205 的 MOS 管，系统地必须取自 `OUT-`；接到 `B-` 会**绕过过放保护**。这是安全问题，不是风格问题。

### 3.2 电机

| # | 网络名 | 连接点 |
|---|---|---|
| N9 | `M_AIN1` | U1.GPIO9, U2.AIN1 |
| N10 | `M_AIN2` | U1.GPIO10, U2.AIN2 |
| N11 | `M_SLP` | U1.GPIO11, U2.nSLEEP |
| ~~N12~~ | ~~`M_FAULT`~~ | **已删除**（2026-08-13）。实物 DRV8833 模块没引出 `nFAULT`，R6 一并删掉，**GPIO38 释放为空闲** |
| N13 | `MOTOR_A` | U2.AOUT1, J1.1 |
| N14 | `MOTOR_B` | U2.AOUT2, J1.2 |

> **网表总数 25 → 24。** U2 的引脚编号也全变了（1×10 单排 → 2×8 双排），本表用的是丝印名，**焊盘号对照见 [选型锁定 §U2 焊盘编号](道闸玩具_底板选型锁定_v1.md)**。

> B 通道不用：`BIN1`/`BIN2` **可以直接悬空**（手册 p3：所有逻辑输入均有 internal pulldown），`BOUT1`/`BOUT2` 悬空。
> `AISEN`/`BISEN` 按模块出厂状态（多数模块已在板上接地）。
> `nSLEEP` 有内部下拉 → **上电默认休眠**，电机不会在主控初始化前乱动，这是好事。

### 3.3 传感与人机

| # | 网络名 | 连接点 |
|---|---|---|
| N15 | `VBAT_DIV` | R3.2, R4.1, C5.1, **U1.GPIO1** |
| N16 | `LIMIT_UP` | U1.GPIO12, **J2.3** |
| N17 | `LIMIT_DN` | U1.GPIO13, **J2.2** |
| N18 | `BTN_UP` | U1.GPIO17, SW1.1 |
| N19 | `BTN_DN` | U1.GPIO18, SW2.1 |
| N20 | `MIC_SCK` | U1.GPIO4, J3.3 |
| N21 | `MIC_WS` | U1.GPIO5, J3.4 |
| N22 | `MIC_SD` | U1.GPIO6, J3.5 |
| N23 | `BUZ_CTL` | U1.GPIO2, R5.1 |
| N24 | `BUZ_BASE` | R5.2, Q1.B |
| N25 | `BUZ_DRV` | Q1.C, J5.2 |

J3 定义：`1=3V3, 2=GND, 3=SCK, 4=WS, 5=SD, 6=GND(L/R)`

> 🔴 **J2 的两个限位端子已对调**（2026-08-14，为消掉 `LIMIT` 那对必然交叉的走线，
> 改的是原理图上 J2 的网络端口）。上表 N16/N17 已按对调后的结果写。
> **接线按此**：J2 第 **2** 脚接**落杆**限位、第 **3** 脚接**起杆**限位。J2.1 是两个开关的公共 GND。
> 依据见[机械约束 §七之三](道闸玩具_底板机械约束_v1.md)。GPIO 侧不受影响。

**共 25 个网络。GPIO7/8/14/15/16/21/47 空闲预留。**

---

## 4. 防砸方案（行程超时反转）

无电流采样，靠时间判定：

- 记录一次完整行程的耗时 `T`（首次 HOMING 时标定）
- 落杆启动后若 **1.15 × T** 仍未触到落位限位 → 判定受阻 → 立即反向抬杆 + 蜂鸣报警
- 若 **1.5 × T** 仍未到位 → 进 FAULT，电机断电

**真实响应延迟**（必须知道）：

| 遮挡时机 | 检测延迟 |
|---|---|
| 行程刚开始就挡住 | ≈ 1.6s |
| 行程中段挡住 | ≈ 0.9s |
| 接近落位才挡住 | ≈ 0.2s |

这期间闸杆压在障碍物上的力约 **1.3N（≈130 克）**——N20 在 5V 下堵转扭矩约 2.0 kgf·cm，除以 150mm 力臂得出。对 6-10 岁儿童不构成伤害风险，但**延迟是秒级不是毫秒级**。

`nFAULT`（N12）是额外的硬件保护通道：过温、过流（2~3.3A）、欠压时芯片自己关断并拉低此脚。注意这个阈值远高于 N20 的实际电流，**它救不了防砸**，只在真正的电气故障时起作用。

---

## 5. 从数据手册核实出的结论

### 5.1 【已修正】v1 把采样电阻放错了位置

DRV8833 手册 p3-4 原文：

| 引脚 | 手册描述 |
|---|---|
| `GND` | "Device ground" |
| `AISEN` | "**Bridge A ground / ISENSE**" · "Connect to current sense resistor for bridge A, or GND if current control not needed" |

**H 桥的电机电流从 `AISEN` 回地，不经过 `GND` 脚。** v1 把 0.33Ω 串在 `U2.GND` 与系统地之间，那里只有芯片静态电流（几 mA），ADC 读不到有效信号，**防砸检测会完全失效**。已删除该电路。

（如果日后换成引出 `AISEN` 的模块或裸芯片：手册 §8.2.2.2 `R_ISENSE = 0.2V / I_CHOP`，V_TRIP 典型 200mV，0.33Ω → 606mA。届时可同时获得硬件斩波限流和快速堵转检测。）

### 5.2 逻辑输入内部下拉

手册 p3：`AIN1/AIN2/BIN1/BIN2/nSLEEP` 均标注 "Internal pulldown"。
→ B 通道输入可安全悬空（v1 写"悬空会乱翻转"是错的）；`nSLEEP` 上电默认低 = 休眠，符合安全预期。

### 5.3 TP4056 充电电流

模块上的 `Rprog` 决定充电电流，标准公式 `I_BAT = 1200 / R_PROG`（Ω→mA）：1.2kΩ→1A，**2kΩ→600mA**，2.4kΩ→500mA。

> ⚠️ 本条**未能从你给的 PDF 核实**——那份 TP4056 手册是扫描件，无法提取文字（正文页提取为空）。上述公式来自 TP4056 通用规格，请以模块实物或卖家标注为准。
> 多数成品模块出厂装 1.2kΩ（1A）。1800mAh 电池按 1A 充是 0.55C，偏大且小空间内发热明显；**建议把模块上那颗 SMD 电阻换成 2kΩ（600mA，0.33C）**，满充约 3.5 小时。

### 5.4 SX1308 与 MT3608 等价

两份手册对比（均为原文）：

| | SX1308 | MT3608 |
|---|---|---|
| 输入 | 2V to 24V | 2V to 24V |
| 开关频率 | 1.2MHz Fixed | 1.2MHz Fixed |
| 内部开关限流 | Internal 4A Switch Current Limit | Internal 4A Switch Current Limit |
| 最大输出 | Up to 28V | Up to 28V |
| 封装 | 6-pin SOT23 | 6-pin SOT23 |
| 标称效率 | up to 96% | up to 93% |

引脚定义相同（SW / FB / EN / VIN / GND）。**成品模块都是 `IN+ IN- OUT+ OUT-` 四焊盘，任选其一即可。** 输出电位器调到 **5.1~5.2V**（补偿 D1 的 0.3V 压降）。

### 5.5 DRV8833 手册要求的外围（模块已自带，确认即可）

| 引脚 | 手册要求 |
|---|---|
| VM | "A 10-μF (minimum) ceramic bypass capacitor to GND is recommended" |
| VINT | "Bypass to GND with 2.2-μF, 6.3-V capacitor" |
| VCP | "Connect a 0.01-μF, 16-V (minimum) X7R ceramic capacitor to VM" |

---

## 6. 布线约束

| 约束 | 原因 |
|---|---|
| **C1(470µF) + C2(100nF) 紧贴 U2 的 VM/GND 引脚**，走线短而粗 | 最容易翻车的地方：N20 启动电流是运行的 3~5 倍，升压输出瞬间塌陷会让主控 brownout 复位，表现为"一按遥控器整机重启" |
| **D1 必须在 C3 之前** | 电机拉低 +5V 时 D1 反向截止，C3 独立供住主控 |
| 电机走线（N13/N14）线宽 ≥ 1mm | 峰值约 800mA |
| 星形地汇于 U3.OUT- 附近一点 | 避免电机地电流流经主控地 |
| **J3（麦克风）走线远离电机走线和 U4 升压模块** | 升压 1.2MHz 开关噪声 |
| ~~SW1/SW2 对齐上盖板 X=-50 / -30 的按键孔~~ | **已作废**。原则反了——**结构让路给 PCB**，不是 PCB 迁就结构。最终按键位置 **SW2 (0,+20)、SW1 (+20,+20)**，见 [机械约束 §七之二](道闸玩具_底板机械约束_v1.md) |
| U3 的 Type-C 口朝 −X 端面 | **功能要求**（充电口必须从前端面插得到），不是结构定死；具体 Y 由 PCB 定，结构开口跟随 |

---

## 7. ~~与结构的接口（CAD 里已定死）~~ —— **整节作废**

> 🔴 **2026-08-14：本节所有数字都已过时，且标题的原则是反的。**
>
> **正确原则：结构让路给 PCB。** 先把板子设计好，再按 PCB 的实际结果改结构——不是反过来。
>
> 下表原值全部作废（板子早已从 146×51 → 100×55 → **120×65**，按键孔从 φ6.5 → **φ9**，坐标全变）：
>
> | 原写 | 现况 |
> |---|---|
> | 板子 146 × 51 | **120 × 65**，x −88…+32，y ±32.5 |
> | 按键孔 X=−50/−30，Y=0，φ6.5 | **SW2 (0,+20)、SW1 (+20,+20)，φ9** |
> | Type-C 开孔 X=−75 | U3 在 (−74.8, **−6**)，本体前沿 x=−88.23 |
> | 总电源开关孔 Y=+19 | SW3 在 (−82.6, **+17**)，拨柄尖 x=−92.01 |
> | 走线孔 (+25,−16.5)，J1/J2/J3 靠近这里 | **J1/J2/J3 已按布线需要分散**，不再统一靠走线孔 |
> | 主控位置 (11,10) | U1 在 (**−16, −8**) rot270 |
>
> **唯一事实源：[机械约束 §七之二 元件坐标](道闸玩具_底板机械约束_v1.md)。**

---

## 8. 尚未确认（按"最常见"假设，到货核对）

| 项 | 当前假设 | 到货要核对 |
|---|---|---|
| DRV8833 模块排针 | 1×10P，丝印 `VM GND AIN1 AIN2 BIN1 BIN2 AO1 AO2 BO1 BO2`，`nSLEEP` 可能标 `SLP`/`STBY`，`nFAULT` 可能标 `FLT` | 排针数量、间距、丝印名 |
| TP4056 模块 | 4 焊盘 `B+ B- OUT+ OUT-` | 丝印是否把 OUT 简写成 `+ -` |
| 升压模块 | 4 焊盘 `IN+ IN- OUT+ OUT-` | 一般无差异 |
| DevKitC-1 | 2×22P，行距 22.86mm | 板子实际排针数 |

**这些不确认就打样是在赌**。但按最常见封装先画，到货后改排母间距参数比重画快得多。

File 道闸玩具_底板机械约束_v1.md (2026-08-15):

# 承载底板 · 机械约束 v2

> 给"转 PCB / 布局"这一步用。**元件尺寸一律以 [元器件尺寸基准 v1](道闸玩具_元器件尺寸基准_v1.md) 为准**，本文只讲结构对 PCB 的约束。

**坐标系**：原点 = 底座几何中心；**+Y = 闸杆伸出侧**，−X = 前端面（Type-C / 总开关 / 按键侧），**X = 车行方向**；Z 向上，Z=0 是底座底面外表面。

> 🔴 **v3.3 改过方向**：原来写的是"+X = 闸杆伸出侧、Y = 车行方向"，闸杆顺着底座长边伸出 —— 整机在 X 上拉到 183+300 = 483mm，**而且根本不是道闸的样子**（真道闸是机箱蹲在路边、杆子横跨路面）。现在闸体绕 Z 转 **+90°**（`HS_ROT = 90`），闸杆沿 **+Y** 伸出。

---

## 一、总体尺寸（已定案）

> 🔴 **2026-08-14 放大：底座 183 × 73 × 25、承载底板 120 × 65。** 原因见 [§七之二](#七之二pcb-布局2026-08-14布局已定稿待布线)。下表已按新值更新。

| 项 | 值 |
|---|---|
| 底座外形 | **183 × 73 × 25** |
| 托盘内腔 | x ±89.5，y ±34.5，地板面 z=2 |
| 上盖 | 厚 3，背面（内腔天花板）z=**22** |
| **承载底板** | **120 × 65 × 1.6** |
| 板底面 z | **4.0**（坐在 4 根 φ4.4 支撑柱上）|
| **板面 z** | **5.6** |

换算关系（改板子尺寸时底座按此跟随）：

```
BASE_L = 板长 + 63     BASE_W = 板宽 + 8
```

---

## 二、板子外形与安装孔

```
        y
   +32.5┌───────────────────────────────────┐
        │╲                                  │
   +27  │ ╲   ○安装孔                 ○     │
        │                                   │
        │                                   │
   -27  │ ╱   ○                       ○     │
        │╱                                  │
   -32.5└───────────────────────────────────┘
        -88                              +32   x
        └ 5×5 切角 ×2（让开底座角螺柱）
```

| 项 | 值 |
|---|---|
| 外形 | x **−88 … +32**（长 **120**），y **−32.5 … +32.5**（宽 **65**）|
| **−X 两角倒角** | 🔴 **45° × 7mm**（2026-08-15 由 5 加大），让开底座角螺柱（螺柱在 (±87, ±32)，φ6）|

> 🔴 **倒角从 5 加到 7 是因为 5 装不进去。** 2026-08-15 第一次把 EDA 里的实际板框读回来和 CAD 对照才发现两件事：
>
> 1. **CAD 一直把这两个角建成 5×5 的方形缺口，而实际板框是 45° 倒角。** 方缺口挖掉的料更多，所以自检 `t=21` 一直显示"没问题"——**CAD 在偏乐观的方向上错了**，这类错误比报错更危险。
> 2. 按真实倒角算：角螺柱中心 (−87, 32) 到倒角斜边只有 **2.47mm**，而螺柱半径 3.0 → **板子会啃进螺柱 0.53mm**。
>
> 倒角要 ≥6.2 才让得开，取 **7** → 净距 **0.89mm**。已确认新增挖除区内没有任何铜，EDA 板框已改、覆铜已重灌、DRC 零错误。
>
> **教训**：文档里的尺寸必须回源头（EDA）验一次。这条和 DevKit 封装行距那次是同一个根因。
| 安装孔 ×4 | φ2.2 **非金属化**，位于 **(−82, ±27)** 和 **(+26, ±27)**；φ4.5 以内不要走线 |
| 安装螺丝 | M2×5 十字盘头自攻 |

**板底只有 2.0mm**：直插件焊脚必须剪到 **≤1.5mm**。0603 / SOT-23 这类贴片件**可以放底面**，建议把 R3/R4/R5、Q1、C2/C4/C5 全挪到底面，给顶面腾地方。

---

## 三、高度预算

| 区域 | 范围 | 天花板 z | **板面以上可用** |
|---|---|---|---|
| **中央区** | \|x\| < 82.75 且 \|y\| < 27.75 | 22.0 | **16.4mm** |
| 止口环下方 | 板子四周约 6.5mm 宽的边带 | 20.0 | 14.4mm |

> 中央区边界 = `(BASE_L−2·WALL−2·GAP)/2 − LIP_W`。2026-08-14 CAD 解冻时更正：
> 这两个数原来写的是 72.75 / 22.75，那是**底座 163×63 时代**的值，底座放大到
> 183×73 后没跟着改。现值由 CAD 参数 `LIP_IN_X` / `LIP_IN_Y` 直接给出。

> 🔴 **中央区里另有两块地被按键帽占了**：上盖背面在 (0,+20) 和 (+20,+20) 各有一个
> **φ14 × 高 2.5 的导向凸台**（底面 z=19.5），给按键帽当导向。那两处板面以上只剩
> **13.9mm**。轻触开关本身顶面才 17.6，让开 1.9mm ✓，但别在按键正下方放高件。

各器件叠高校核：

| 器件 | 叠高 | 余量 |
|---|---|---|
| U1 DevKit + **低背 5.0 排母** | 12.17 | ✅ 4.2 |
| U2 DRV8833 + 低背 5.0 排母（模块高 5.0）| 12.5 | ✅ 3.9 |
| U3 TP4056 **贴板直焊** | 4.8 | ✅ 11.6 |
| U4 MT3608 **贴板直焊**（**37×17**×7）| 7.0 | ✅ 9.4 |
| C1 φ6.3×11 / C3 φ5×11 | 11 | ✅ 5.4 |
| SW1/SW2 轻触 6×6×12 | 12 | ✅ 顶杆本来就要伸进上盖孔 |
| J1/J2/J4 KF128-3.81 | ~9.5 | ✅ |

> **排母只买低背 5.0mm。** DevKit 叠高是四层：排母 5.0 + DevKit 排针塑料隔片 **2.5** + DevKit 板 1.57 + 模组 3.1。用常见的 8.5mm 排母就是 15.67mm，余量几乎为零。

---

## 四、位置约束（**结构让路给 PCB**，不是反过来）

> 🔴 **2026-08-14 用户更正了本节的原则。** 原标题写的是"结构已开孔，PCB 迁就"——**这是反的**，与[尺寸基准](道闸玩具_元器件尺寸基准_v1.md)里定的"**先以板子尺寸为主，结构件随板子调整**"自相矛盾。
>
> **正确顺序：先把电路板设计好，再按 PCB 的实际结果去改结构尺寸。**
> 安装孔位置、按键位置、卧式开关位置**都可以为布线让路**，最后以 PCB 定稿的实际坐标反推结构。
>
> 仅有的软性要求（不是硬约束）：
> - 两个按键**尽量在同一条水平线上**（同一 Y），且不要太偏
> - 卧式开关（SW3）位置可适当调整
> - **整体上不要大动**，保持外观比例合理
>
> 下表是**当前 PCB 定稿后的实际值**，供结构跟随，不是给 PCB 的约束。

**元件的实际坐标只有一份，在 [§七之二 元件坐标](#元件坐标v3-定稿按可布线性重排)。** 本节不再重复列表（曾经重复过，结果两处对不上）。

结构需要跟随的接口，只有这几条：

| 结构特征 | 依据 PCB 的哪个元件 | 当前值 |
|---|---|---|
| 上盖 φ9 按键孔 ×2 | SW2（落杆）/ SW1（起杆）| **(0, +20)** 和 **(+20, +20)**，同一 Y，间距 20 |
| 前端面 Type-C 开口 | U3 | 座中心 y ≈ **−6**、z ≈ 8；本体前沿 x = −88.23。**开口 12.5×8.0**（按插头塑料头 11×6.5 开，见 §287）|
| 前端面拨柄开口 | SW3 | 拨柄尖 x = **−93.51**、中心 y ≈ **+17**、z ≈ 8。露出外壁 **2.01mm** ✅ |
| 上盖充电灯观察孔 | U3 的两颗指示灯 | CAD 已开在 **(−80, 0) 的 10×6 长圆窗** ✅ 位置由用户按实物给定（原 (−84,−6) 是"指示灯紧邻 Type-C 座"的猜测值，已作废）|
| 上盖走线孔 | J1 电机 / J2 限位 / J3 麦克风 | 三者已按布线需要分散，**不再统一靠 +X 板边**；走线孔位置按闸体位置定即可，内部飞线长一点无妨。CAD 实建 **(55, −16.5)**，在电池上方 |
| **闸体位置** | SW1 起杆按键 / 底座 +X 边 | 🔴 **`HS_X_ABS = 51.5`，绕 Z 转 +90°**（占 x 28.5…74.5，占位是 46×46 正方形，转 90° 不变）。<br>51.5 是**反推出来的**：转轴不在闸体中心——夹杆臂占闸体局部 y −35…−24，整段悬在 −Y 面外侧；转 90° 后甩到局部 +X，外沿落在 `HS_X_ABS+35`，要离底座 +X 边（91.5）留 5mm。<br>离 x=20 那颗按键帽 φ12.5 沉孔的边（26.25）还有 2.25mm。历史：v2.6 在 x=25 时闸体整个盖住那颗按键 |
| 底板支撑柱 ×4 | 安装孔 | **(−82, ±27) (+26, ±27)** |

> **按键 y 的约束**：φ9 的孔要整个待在中央区，顶杆才不会撞止口环；同时要让开 27.94 宽的 DevKit。当前取 y=+20，DevKit 顶边在 +5.97，让开 ✓

---

## 五、~~建议分区~~（已作废，被 §七之二 的实际布局取代）

> 本节原按 100×55 的板子做的分区建议，板子已放大到 120×65 且布局已按可布线性重排完成，**这张分区表全部作废**。以 [§七之二 元件坐标](#元件坐标v3-定稿按可布线性重排) 为准。
>
> 唯一仍成立的一条经验：**贴片矮件不必占板面**——DevKit / DRV8833 插排母后架空 7.5mm，0603 / SOT-23 / SMA 可以直接放在模块肚子底下（**11mm 高的电解电容 C1/C3 不行**）。当前布局已用上这一点。

---

## 六、托盘那边的让位（别撞）

> 下表是 **CAD v3.0 实建值**（2026-08-14 解冻后回写，与 `cad/daozha.scad` 一致）。

| 特征 | 位置 | 高度 z |
|---|---|---|
| 角螺柱 ×4 | (±87, ±32)，φ6 | 1 → 19.8 |
| 底板支撑柱 ×4 | **(−82, ±27) (+26, ±27)**，φ4.4 | 0 → 4 |
| 电池仓 −X 挡边 | x 33…36 | 1 → 12 |
| 电池仓 ±Y 挡边 | **y ±18…±21**（贴着电芯放 1mm，不是贴内壁）| 1 → 12 |
| 电池 103450（成品）| x 36…87，y ±17 | 2 → 12 |
| 闸体固定螺丝头 | **(40,±15) (70,±15)** | 沉平在上盖背面 z=22，**不伸进腔内** |
| 走线孔（上盖）| **(55, −16.5)**，φ8 | 贯穿上盖 |
| 按键帽导向凸台 ×2（上盖背面）| (0,+20) (+20,+20)，φ14 | 19.5 → 22 |
| 充电灯观察窗（上盖）| (−84, −6)，10×6 长圆 | 贯穿上盖 |

> 🔴 **闸体从 x=25 挪到 x=55**（占 x 32…78）。原因：PCB 定稿的起杆按键在 x=+20，
> 而闸体原来占 x=2…48，**整颗按键被闸体盖住，手指够不到**。按"结构让路给 PCB"
> 只能挪闸体。连带上盖走线孔从 (25,−16.5) 挪到 (55,−16.5) —— 落在电池上方，
> 闸体下来的飞线贴电池顶面（有 10mm 空隙）往 −X 走到板上，与电池自己的引线同路。
>
> ⚠ 原表里 (±31…±34) 的电池仓 ±Y 挡边是错的：那个位置贴着内壁，电芯会在 Y 向
> 晃 14mm。实建按"比电芯每边放 1mm"取 ±18…±21。

---

## 七、EDA 里必须先改掉的 3 处封装 + 1 条网络

**转 PCB 之前先做完这些，否则焊盘全错。**

| # | 位号 | 改什么 | 状态（2026-08-13 晚）|
|---|---|---|---|
| 1 | **SW3** | 器件换 **SK12D07VG7**，信号脚间距 **2.54 → 2.0**，另有两端固定脚，总跨 8.3 | ✅ **已做**。系统库器件 `SK-12D07VG7`，焊盘实测 2.0 / 8.3 全对 |
| 2 | **U2** | 封装 1×10 单排 → **2 排 × 8 脚**，排间距 **15**（建议画椭圆焊盘吸收 15/15.24 差异）| ✅ **已做**，自建封装，排距取 **15.24**（见下）|
| 3 | **U4** | 封装 1×4 排母 → **四角 4 个焊盘**，通孔 φ**1.651**，焊盘 4×4mm；模块外形 **37×17**（原写 36，已按实物图更正）| ✅ **已做**，孔距实测 **30 × 7**，自建封装 |
| 4 | **N12 / R6** | **删除**。`M_FAULT` 网络和 10kΩ 上拉都不要了——实物 DRV8833 模块没引出 `nFAULT` 脚。**GPIO38 释放为空闲** | ✅ **已删** |

> J3（麦克风）**不用改**，2.0mm 本来就对——麦克风在闸体上靠飞线接过来，间距不需要与模块一致。

### U2 排距为什么取 15.24 而不是 15

原文建议"用椭圆焊盘吸收 15/15.24 差异"，但这条**推理链其实不成立**：模块靠两条 1×8 排母插着，排母条本身是刚性的、脚距固定 2.54，**我们板上焊盘的形状根本影响不到模块能不能插进去**——那个 0.24mm 是由排母插孔自身的顺应量吃掉的，不是由焊盘吃掉的。

真正该定对的是**孔位**。8 个脚必然落在 0.1″ 栅格上，所以 **6 × 2.54 = 15.24** 才是物理上说得通的数，"15" 应是读数取整。已按 15.24 建封装；φ1.0 孔对 0.5mm 排母针本身有 ±0.25mm 余隙，两种说法都能插。
椭圆焊盘照做了（2.2 × 1.8，长轴沿排距方向），当作铜箔余量，不当作公差补偿。

**打样前拿卡尺复核一次两排针中心距**；若确为 15.0，把封装两列 x 从 ∓7.62 改成 ∓7.5 即可。

### ✅ U4 孔距已实测：30 × 7

| | 值 | 每边余量 |
|---|---|---|
| 长边（36）方向两孔中心距 | **30** | 3 |
| 短边（17）方向两孔中心距 | **7** | 5 |

焊盘坐标 **(∓15, ±3.5)**，孔 φ1.651（=65mil），焊盘 4×4。封装：个人库 `MODULE-TH_MT3608-37x17-4PAD`。
**模块外形是 37 × 17，不是 36**（实物尺寸图，见尺寸基准）。
原理图 U4 符号是 4 脚、**没改**，只换了封装，四条连接改前改后完全一致。
**正极排布已按实物确认**："+"走一条长边、"−"走另一条。

> ⚠ **PCB 布局时要注意一件事**：焊盘 4×4 而短边孔距只有 7 → **两焊盘边缘只剩 3mm 净距**，且焊盘外缘到模块短边只有 (17−7)/2−2 = **3mm**。布局时 U4 下方尽量不要走线，避免大焊盘的热量和铜箔挤占。
> ⚠ **转 PCB 后顺手核一下 U4 丝印外框是 37 还是 36**（工程库副本可能没跟着更新，焊盘无差异）。见 [尺寸基准 §遗留](道闸玩具_元器件尺寸基准_v1.md)。

---
## 七之二、PCB 布局（2026-08-14，已定稿）

### 🔴 板子和底座放大了：120 × 65（底座 183 × 73 × 25）

原 100×55 装不下。根因是 **U4 实测 37mm 长**，而当初定 100×55 时 U4 假设的还是 SX1308（23×16.3）——这 14mm 是一整块刚性尺寸，挪不动也拆不开。

100×55 上算过的死结：U4 需要 37mm 连续跨度，而板上唯一够长的位置被 SW2（按键孔钉死）和右安装孔夹成 **34.8mm**，差 3.2mm。硬塞需要把安装孔挪到离板边只剩 1.4mm 板材，且全板只剩 0.3mm 级间隙。

用户拍板放大。**120 × 65**：占用率 71% → **51%**，最小间距回到 0.87mm 以上。

| | 原 | 新 |
|---|---|---|
| 承载底板 | 100 × 55 | **120 × 65** |
| 底座（按 `BASE_L=板长+63`、`BASE_W=板宽+8`）| 163 × 63 × 25 | **183 × 73 × 25** |
| 板子占位（原点=底座几何中心）| x −78…+22, y ±27.5 | **x −88…+32, y ±32.5** |
| 安装孔 ×4 | (−70,±23) (+16,±23) | **(−82,±27) (+26,±27)** |

−X 两角仍是 **5×5 切角**。安装孔 φ2.2 **非金属化**。

### ⚠ 按键位置最终定为 (0, +20) 和 (+20, +20)

历史上三份文档给过三组值，全部作废：本文档 v2 写 (−45,+12)(−25,+12)，[网表基准](道闸玩具_底板网表基准_v2.md) 和[需求书](道闸玩具_需求规格说明书_v2.md)写 X=−50/−30，中途还统一过一次 (−50,+12)(−30,+12)。

**布局 v3 按可布线性重排后，最终值是 SW2 (0, +20)、SW1 (+20, +20)** —— 同一 Y、间距 20mm，紧邻 U1 的 `BTN_DN`/`BTN_UP` 引脚。上盖 **φ9** 按键孔按此开（不是旧文档写的 φ6.5）。
### 元件坐标（v3 定稿，按可布线性重排）

**排布依据：外围件的左右次序 = U1 那排引脚的次序。** U1 有 14 个信号挤在同一排，从左到右是：

```
GND · 5V_MCU · LIMIT_DN · LIMIT_UP · M_SLP · M_AIN2 · M_AIN1 · … · BTN_DN · BTN_UP · … · MIC_SD · MIC_WS · MIC_SCK · 3V3
```

所以上方外围件从左到右依次是 **J2(限位) → U2(电机驱动) → SW2/SW1(按键) → J3(麦克风)**，飞线基本不交叉。
另一排只有 `BUZ_CTL` 和 `VBAT_DIV` 两个信号（在 U1 下方），对应的 Q1/R5/LS1 和 R3/R4/C5 就放在 U1 底下那条带。

| 位号 | x | y | rot | 说明 |
|---|---|---|---|---|
| **U3** TP4056 | −74.8 | −6 | 0 | Type-C 朝 −X，本体前沿悬出板边 0.23 |
| **SW3** 拨动 | **−84.1** | +17 | 270 | 拨柄尖 x=**−93.51**，露出外壁 2.01mm。🔴 原来在 −82.6，拨柄只露 0.51mm，**不满足尺寸基准 §366 定的 1mm 判据**——那张 H 选型表是按老底座（外壁面 −75）算的，底座放大到 183 后没回头重算。物料已买齐换不了 H，改成往 −X 挪 1.5mm 补回来（焊盘到板边仍有 3.9mm）|
| **U4** MT3608 | −60 | +23.5 | 0 | 靠左，紧邻 `VBAT_SW` 的来源 SW3 |
| **J2** 限位 | −58 | +10 | 0 | |
| **C3** 220µF | −46 | +10 | 0 | 11mm 高，不能放模块底下 |
| **U2** DRV8833 | −31 | +20 | 0 | 正对 U1 的 `M_AIN1/2`、`M_SLP` |
| **C2** 100nF | −26 | +27.3 | 0 | **在 U2 肚子底下**，紧贴 VM/GND |
| **C1** 470µF | −17.5 | +28 | 0 | 距 U2 的 VM 焊盘约 6mm |
| **J1** 电机 | −13 | +18 | 0 | 紧邻 U2 的 AO1/AO2 |
| **U1** DevKit | −16 | −8 | 270 | 占 x[−47.81,+15.81] y[−21.97,+5.97] |
| **SW2** 落杆 | 0 | +20 | 0 | 与 SW1 **同一 Y**，间距 20mm |
| **SW1** 起杆 | +20 | +20 | 0 | 同上 |
| **J3** 麦克风 | +22 | +9 | 0 | 远离电机走线与 U4 |
| **J4** 电池 | +24 | −10 | 0 | 靠 +X 板边 |
| D1 | −40 | 0 | 0 | **U1 肚子底下** |
| C4 | −34 | 0 | 0 | U1 肚子底下 |
| R5 | −5 | −16 | **180** | U1 肚子底下；转 180° 是为了让 BUZ_CTL/BUZ_BASE 不交叉 |
| C5 | 0 | −16 | 0 | U1 肚子底下 |
| R3 | +5 | −16 | 0 | U1 肚子底下，紧邻 U1 的 ADC 脚 |
| R4 | +9 | −16 | 0 | U1 肚子底下 |
| Q1 | −4 | −24.6 | 0 | |
| LS1 蜂鸣器 | **+7** | −27.2 | 0 | |

> **利用了模块架空的空间**：DevKit 插 5.0 排母后板底离板 **7.5mm**，0603 / SOT-23 / SMA 这类矮件可以直接放在它（以及 U2）肚子底下。**C1 / C3 是 11mm 高的电解电容，不行。**

### 布局质量

| 指标 | 结果 |
|---|---|
| **总 HPWL**（各网络包围盒半周长之和）| **1711 → 1010 mm，改善 41%** |
| `MOTOR_A` / `MOTOR_B` | **99/105 → 12/13 mm** ✅ 文档要求"短而粗"的两条 |
| `VBAT_DIV`（ADC 高阻节点）| 126 → 14 mm ✅ |
| `BUZ_CTL` | 71 → 11 mm ✅ |
| 元件重叠 | **0** |
| 最小间距 | **0.93mm** |
| 焊盘全部在板内 | ✅ 最小边距 1.47mm（U3.5）|
| 安装孔净空冲突 | **0** |

### 🔴 安装孔"净空 0 冲突"不等于螺丝拧得下去（2026-08-15 补）

上面那行只查了"孔里有没有东西"，**没查螺丝头底下压着什么**。复核发现：

- 四个孔位 **(−82,±27)、(26,±27)** 与 CAD `PCB_MNT` **零偏差**；孔径 **φ2.200 非金属化孔**（焊盘=孔径无环），M2 φ2.0 单边 0.1mm ✅
- 🔴 但 **(−82,27)** 那个孔，`VBAT_SW` 走线铜边离孔心只有 **1.50mm**；而覆铜区是矩形 `["R",−3340,1165,4515,2315]` mil（x −84.84…29.85、y −29.21…29.59），**四个孔全在里面**，板上没有任何禁铺铜区。
  M2 盘头 φ3.5~4.0（半径 1.75~2.0）→ **螺丝头同时压住 `VBAT_SW` 和 GND 覆铜，中间只隔一层阻焊**。拧紧压破阻焊 = **电池正极对地短路**，而 `VBAT_SW` 是拨动开关之后的电池正极，全程无限流。
- **已修**：`VBAT_SW` 的拐角从 x=−80 挪到 **−78.5**（并补一段 (−80,17)→(−78.5,17) 保住 T 型接点）→ 净距 **1.50 → 3.00mm** ✅。其余三孔 4.69 / 9.29 / 13.64mm 本来就够。
- 判据：**孔心到任何非 GND 铜箔 ≥ 2.5mm**（螺丝头半径 2.0 + 0.5 位置公差）。

> **教训**：这类"孔位完全对齐但装不了"的问题，孔位表怎么查都查不出来 —— 要查的是**螺丝头投影范围内有什么**。

> ⚠ **唯一变长的网络是 `VBAT_SW`（81 → 131mm）**，这是有意的取舍：R3 必须靠近 U1 的 ADC 脚以缩短 `VBAT_DIV`——那是 100k/100k 分压的高阻节点（源阻抗 50k），怕噪声；而 `VBAT_SW` 是低阻电池轨，走长一点无害。

### 🔴 U1 DevKit 封装的行距是错的，已修正

系统库 `CONN-TH_ESP32-S3-DEVKITC-1U-N8` 两排焊盘间距 **22.86mm**，而卖家尺寸图明确标 **25.400mm**（板宽是另一个标注 27.940）。
几何上也是尺寸图对：27.94 板宽配 25.4 行距 → 每排距板边 1.27mm，排针本体正好与板边齐平。**照库封装打样，DevKit 插不进去。**

已复制到个人库改为 `CONN-TH_ESP32-S3-DEVKITC-1-N16R8_S25.4`，44 个焊盘 X 从 ±11.43 → **±12.7**。新建器件 `ESP32-S3-DevKitC-1-N16R8-行距25.4` 沿用原符号，故原理图 20 根导线一根未动，网表逐条比对完全一致。

> ⚠ 该封装的**丝印**是非线图元画的，API 读不到也改不了，外框仍按旧板宽画，比实际窄。不影响电气与装配，只是目视参考偏小。

### ⚠ U3 的「悬出板边 2mm」做不到，实际 0.23mm

`PWRM-TH_TP4056` 里 IN+/IN−（脚 5/6）距原点 11.73，而本体前沿距原点 13.43 —— 本体只比最外侧焊盘多伸 1.7mm。要悬出 2mm 这两个焊盘就掉到板外了。
现取本体前沿与板边基本齐平（U3 在 x=−74.8，本体前沿 −88.23，悬出板边 0.23）。

> 🔴 **原来这里写的"USB-C 插头长约 6.5mm，穿 2mm 壁 + 1.7mm 间隙仍插得到底"是错的**（2026-08-15 复核推翻）。
> 那句话只比了"插头长度 > 死区"，**漏了插头的塑料头也得跟着钻进去** —— Type-C 完全插入时塑料头前端面基本贴住座口。
> 从外壁面 −91.5 到座口 −88.23 有 **3.27mm 死区**，塑料头（实测 **11 × 6.5**）过不去 10×5 的开口就会顶在外壁上，
> 金属壳只能进 6.5 − 3.27 ≈ **3.2mm，约一半，接触不上**。
> **修法：开口按塑料头开，不是按金属壳开** —— `USB_W/H` 10×5 → **12.5×8.0**（`USB_Z` 8 → 8.5）。遥控器同理，死区 3.5mm，`RC_USB` 10×4.5 → 12.5×8.0。
> 自检 `t=80..83` 钉死这条，阳性对照是"塑料头放大到 14×9 必须被挡住"。

### ⚠ 两个通用教训

1. **`getPrimitivesBBox()` 把位号文字也算进去**，不能当实体尺寸用（U2 丝印 18.1 宽，包围盒报 21.08）。算净距必须用实体尺寸。
2. **元件间距不能只比单轴**。两个盒子在 X、Y 都不重叠时是对角相邻，真实间距是对角线长度，只看 X 会误报成"几乎贴住"。

---

## 七之三、PCB 布线（2026-08-14，**已完成，DRC 零错误**）

### 结果

| 项 | 值 |
|---|---|
| 走线 | **105 段**，双面 |
| **过孔** | **0**（全部靠 THT 焊盘换层）|
| 覆铜 | **顶层 + 底层各一块 GND** |
| **DRC** | **✅ 零错误**（`pcb_Drc.check(true,false,true)` 返回空数组）|
| 独立连通性复核 | ✅ 23 条信号网络全部连通 |

线宽按电流分档：**电机 1.0mm**、**电池回路 1.0mm**、`+5V` 0.6mm、其它电源 0.4~0.5mm、信号 0.3mm。

#### 🔴 复核发现：电池回路原线宽不够，已加粗

按 IPC-2221（1oz 外层、10°C 温升）核算，最坏工况是**电机峰值 800mA + 电池 3.0V 低电量**：
升压输入端电流 = 5.1 × 0.8 ÷ 0.93 ÷ 3.0 ≈ **1.46A**。

| 网络 | 原线宽 | 承载能力 | 判定 | 现改为 |
|---|---|---|---|---|
| `VBAT_PROT` / `VBAT_SW` | 0.5mm | 1.45A | ❌ **不足** | **1.0mm**（2.39A）|
| `BAT+` / `BAT-` | 0.6mm | 1.65A | ⚠ 仅余 13% | **1.0mm** |

> **注意**：电池侧电流**大于** +5V 侧（1.46A vs 0.8A），因为升压是降流升压。容易只盯着输出侧而漏掉输入侧。

### 关键网络的走线依据

| 网络 | 层 | 线宽 | 依据 |
|---|---|---|---|
| `MOTOR_A` / `MOTOR_B` | 顶 | **1.0** | 网表基准要求 ≥1mm；布局已把长度压到 12/13mm |
| `+5V` → U2 的 VM | 顶 | 0.6 | "最容易翻车的地方"：C1/C2 紧贴 VM，走线短而粗 |
| `BAT+` / `BAT-` | 底 | **1.0** | 电池主回路（审核后加粗，见下）|
| `GND` | **两面覆铜** | — | 22 个 GND 焊盘全靠它；星形地的实现方式 |

### 🔴 J2 的两个限位端子对调了（改了原理图）

`LIMIT_UP`/`LIMIT_DN` 原本必然交叉：J2 上的源顺序与 U1 上的目标顺序是**反的**。

限位开关是**靠飞线接到 J2**的，哪个端子接哪个信号完全自由。于是把原理图里 J2 的网络端口对调：

| | 改前 | **改后** |
|---|---|---|
| J2.2 | LIMIT_UP | **LIMIT_DN** |
| J2.3 | LIMIT_DN | **LIMIT_UP** |

改完源序与目标序一致，交叉消失，两条线同层平行走完，**省掉一个过孔**。

> ⚠ **接线时注意**：J2 的第 2 脚接**落杆**限位、第 3 脚接**起杆**限位。装配文档要按此写。

### 为什么最终 0 过孔

`pcb_PrimitiveVia.create()` 建出来的过孔，位置/网络/类型（通孔）/尺寸全部正确，加大到 0.9mm 重建后 **EDA 仍报"该走线与同网络其它对象断开"**，即不承认它导通。原因未查明。

绕开办法：**所有换层都发生在 THT 焊盘上**（THT 焊盘天然贯通两层，不需要过孔）。为此做了两处调整：

- `VBAT_PROT` 改走底层（两端 SW3.1 / U3.1 都是 THT），让出顶层给 `VBAT_SW` 全程走完
- J2 端子对调（见上），消掉 `LIMIT` 那对交叉

### 自动布线不可用

`pcb_Document.autoRouting()` 无论带不带参数、指定单条网络与否，**一律返回 24 条全部失败、`duration: 0`**，不产生任何铜。界面上点按钮则报「请先绘制板框」。

但**板框是好的**：`zoomToBoardOutline()` 返回 true、3D 预览能生成（3D 必须有板框）、6 段线端点严丝合缝闭合。判断是该功能自身受限（云端服务/授权），**不是板框问题**。改 API 建单个闭合图元也走不通——`Polyline`/`Region`/`Pour` 都要 `IPCB_Polygon` **对象**，而该对象无公开构造方法。

### 覆铜必须手工画 + 画完要重建

同样因为 `IPCB_Polygon` 无法构造，**覆铜只能在界面上画**（顶层、底层各一块，网络 GND，比板框内缩约 0.5mm）。

⚠ **画完必须重建**：`IPCB_PrimitivePour.rebuildCopperRegion()`，否则铜箔与走线间距为 0，等于把底层全部短接到 GND。

⚠ **底层覆铜够不着顶层贴片的 GND 焊盘**（C2.2 / C4.2 / C5.1 / Q1.2 / R4.1），所以**两面都要铺**。

### 布线方法：先算后画

写了两个校验脚本，**在下笔之前**算间距，通过了才创建：

| 脚本 | 作用 |
|---|---|
| `clearance.js` | 每段走线对**所有异网焊盘**和**同层异网走线**算实际净距，阈值 0.2mm |
| `connect.js` | 用**回读的实际铜箔**重建连通性，确认每条网络的焊盘真的在同一连通块 |

**它一共拦下 30+ 处问题**，其中三处是校验模型自身的缺陷，值得记住：

1. **U1 的 24 个未用引脚也要避让** —— 漏算后 `BUZ_BASE` 撞 U1.38、`VBAT_SW` 撞 U1.42。U1 两排焊盘是 2.54 满排，**穿越只能走 1.02mm 的缝**（0.3mm 线居中约剩 0.36mm）
2. **贴片焊盘只在顶层**，不该双面阻挡（修正后消除 8 处误报）
3. **安装孔是独立焊盘**，`getAllPins()` 取不到 —— 漏算后 `VBAT_SW` 蹭到 MH1，是 DRC 抓出来的

## 八、变更记录

| 版本 | 日期 | 说明 |
|---|---|---|
| v1 | 2026-08-12 | 首版，底座 150×55×22，板 87×47 |
| **v2** | **2026-08-13** | 底座放宽到 **163×63×25**、板 **100×55**；净空 13.4→**16.4**；升压改 MT3608 摊明面直焊；DRV8833 高 5 可插排母；按键孔 φ6.5→**φ9** 且位置改 (−45/−25, +12)；新增"TP4056 指示灯不可被 DevKit 遮挡"；J3 不用改封装（更正） |
| **v2.1** | **2026-08-14** | 板 **120×65** / 底座 **183×73×25** 定稿，PCB 布局布线完成（§七之二、§七之三）|
| **v2.2** | **2026-08-14** | **CAD 解冻到 v3.0 后回写实建值**：§三 中央区边界更正为 ±82.75/±27.75（原来还是 163×63 时代的 72.75/22.75）；§六 全表按实建更新，电池仓 ±Y 挡边由 ±31…±34 更正为 **±18…±21**（原值贴着内壁，电芯会晃 14mm）；新增按键帽导向凸台和充电灯观察窗；🔴 **闸体 x=25 → 55**（原位置整个盖住 x=+20 那颗按键）|

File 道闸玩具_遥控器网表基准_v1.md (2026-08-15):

# 道闸玩具 · 遥控器 网表基准 v1

> 依据：`道闸玩具_电路与结构设计方案_v2.md` §4.2、`道闸玩具_元器件尺寸基准_v1.md`
> **用途**：画原理图 / PCB 之前的"正确性基准"。画完后用 EDA API 读回实际网表，与本文逐条比对。
> 主机那块板就是这么做的（24 条网络逐条比对），**别跳过这一步**。

2026-08-15 用户拍板三条，直接砍掉了一半电路：

| 决定 | 后果 |
|---|---|
| **不做状态灯** | 不用 WS2812 / 不用板载 LED，上盖不开灯孔。顺带了结了"WS2812 还是普通 LED"的文档打架 |
| **不做电量检测** | 删掉 100k/100k 分压 —— 它静态就吃 **18.5µA**，而深睡指标 <20µA，遥控器只有 250mAh。**BOM 里一颗电阻都不需要了** |
| **外壳尺寸可动** | 优先保证装得下，见尺寸基准 §遥控器内腔核算（目标 68 × 32 × 22）|

---

## 1. 板子定位

**载板**：现成模块（C3、TP4056）焊在板上，三个按键和拨动开关也焊在板上，电池垫在板底下。

- 板子外形**由布局决定**，不预先框死 —— 外壳跟随板子（项目原则：结构让路给 PCB）
- **元件高度预算：板面以上 ≤ 6.9mm**。最高的是 C3 的 USB-C 座（叠高 6.7）
- 🔴 **不能用 KF128 接线端子**：它高 9.5mm，直接超预算。电池引线**焊在板上的两个焊盘**上

---

## 2. 元件位号表

| 位号 | 器件 | 说明 |
|---|---|---|
| U1 | **ESP32-C3 SuperMini** | 主控，22.52 × 18 |
| — | **2.54 低背排母 5.0mm，1×8 ×2** | 🔴 **给 U1 用，必须低背 5.0**（同主机）。模块要反复拔下来改程序，**不能直焊** |
| U2 | **TP4056 Type-C 模块（带 DW01+FS8205 保护）** | 28 × 17，充电口就是它的 Type-C |
| SW1 | 6×6 轻触开关 | **抬杆** |
| SW2 | 6×6 轻触开关 | **落杆** |
| SW3 | 6×6 轻触开关 | **复位** |
| SW4 | **SK12D07VG7 拨动开关**（卧式侧拨） | 总电源。🔴 不是立式的 SS12D00 |
| C1 | 10µF / 16V **0805 陶瓷** | V5 轨储能，**贴板底面**。见 §4.3 |
| P1 / P2 | 焊盘（非端子） | 电池 +/− 引线 |

**轻触开关高度待定** —— 要等板面 z 定了才能选，见 §5.2。

### EDA 选型锁定（2026-08-15 已建工程并连线）

工程 **`道闸玩具遥控器`**，uuid `ea4e1a7afdae48fc87c730f80a6c9114`（Board1 / Schematic1 / PCB1）。

| 位号 | 器件名 | 封装 | device uuid |
|---|---|---|---|
| U1 | **ESP32-C3 SuperMini_TH** | `COMM-TH_ESP32-C3-SUPERMINI_TH` | `1fc07a0a91f44aafa9d865ca6eb59e38` |
| U2 | TP4056充电源模块板(Type-C) | `PWRM-TH_TP4056` | `3aa84456264e47708e126cdf52ec3c68` |
| SW1/2/3 | 轻触开关6X6X12 | `SW-TH_4P-L6.0-W6.0-P4.50` | `00ec1270e33944788eff4adebd5b6ca7` |
| SW4 | SK-12D07VG7 | `SW-TH_SK-12D07VG7` | `134d2d15e32949759c530cbf1dbeca16` |
| C1 | CL21A106KAYNNNE_C15850（10µF 25V）| `C0805` | `8c1f4a9e9d204b148b36ce719c891bd1` |
| P1 | HEAD2（1×2 P2.54）| `HDR-TH_2P-P2.54-V-M` | `75deb6b8f00547acbb71a567c2dd03b2` |

**U1 选直插版（`_TH`）不是贴片版**：库里两个都有（贴片版 `70fbe3e829f842f390c40919da2703fb`）。

### 🔴 U1 必须插排母，不能直焊（2026-08-15 用户确认）

模块要反复拔下来改程序。**封装不用改** —— 16 个 2.54 通孔、行距 15.24，排母直接焊进同一组孔，模块再插上去。但叠高变了：

| | 直焊 | **插低背排母 5.0** |
|---|---|---|
| 排母本体 | — | 5.0 |
| 模块排针塑料隔片 | 2.5 | 2.5 |
| 模块 PCB | 1.0 | 1.0 |
| USB-C 座 | 3.2 | 3.2 |
| **合计** | 6.7 | **11.7** |

**外壳因此从 22 长到约 26 高。** 顺带一个好处：模块被架空 **7.5mm**，天线离铜箔远了，射频条件反而改善（主机的 DevKit 就是这个情况）。

⚠ **按键跟着受影响**：板面 11.1、盖面 26 → 顶杆要够到 **14.9mm**。6×6 轻触最高只到 13 左右，**必须配打印按键帽**，和主机一样。

**P1 用 1×2 排针封装当焊盘用**：不装排针，电池引线直接焊进两个孔。

**不能用 KF128 端子**——它高 9.5mm，而板面以上原本只有 6.9mm 的预算（插排母后虽然涨到 11.7，但那是给 U1 的，电池焊盘该矮还得矮）。

### ✅ 封装几何已核对（2026-08-15，转 PCB 后从 PCB 文档读焊盘坐标）

系统库封装读不了几何（`lib_Footprint.get` / `.copy` 都抛不透明错），所以是**导入 PCB 之后**从焊盘坐标反算的：

| 封装 | 读回值（相对元件中心） | 判定 |
|---|---|---|
| **U1** `COMM-TH_ESP32-C3-SUPERMINI_TH` | 两排焊盘 x = ∓7.62 → **行距 15.24**；每排 8 脚 P2.54，跨距 17.778 | ✅ **用户卡尺实测确认 15.24**。板宽 18 → 每排距板边 1.38mm，几何自洽 |
| SW4 `SW-TH_SK-12D07VG7` | 信号脚间距 **2.0**、固定脚总跨 **8.3** | ✅ 与规格书一致 |
| SW1-3 `SW-TH_4P-...-P4.50-LS6.1` | x 跨 **6.10**、y 跨 **4.50** | ✅ 并证实**左右两列各自内部导通**（1/3 一侧、2/4 另一侧），与"脚1=信号、脚2=GND"的接法一致 |
| C1 `C0805` | 焊盘间距 2.0 | ✅ |
| P1 `HDR-TH_2P-P2.54-V-M` | 2.54 | ✅ |
| U2 `PWRM-TH_TP4056` | 焊盘跨 23.45 × 14.36（本体 28×17，四周内缩合理）| ✅ |

> **主机栽过的坑在这里没有重演**：DevKit 那次系统库给 22.86、实物 25.4，照库打样插不进去。
> 这次 15.24 = 0.6 英寸，是 DIP 标准值，且与 18mm 板宽自洽；用户实物量过，闭合。

---

## 3. 网表（8 条网络）

| # | 网络名 | 连接点 |
|---|---|---|
| N1 | `VBAT` | 电池+ (P1) → U2.**B+** |
| N2 | `VBAT_N` | 电池− (P2) → U2.**B−** |
| N3 | `VSYS` | U2.**OUT+** → SW4.公共脚（中间脚）|
| N4 | `V5` | SW4.常通脚 → U1.**5V**，C1.1 |
| N5 | `GND` | U2.**OUT−**，U1.**GND**，SW1.b，SW2.b，SW3.b，C1.2 |
| N6 | `BTN_UP` | SW1.1 → U1.13 = **GPIO4** |
| N7 | `BTN_DN` | SW2.1 → U1.12 = **GPIO3** |
| N8 | `BTN_RST` | SW3.1 → U1.10 = **GPIO1** |

> **为什么是 4/3/1 而不是原计划的 3/4/5**：库里 SuperMini 符号把 GPIO0~4 放在**右侧一列**（引脚 9~13），而 **GPIO5 在左侧**（引脚 1）。三个按键都在右边，用 GPIO5 就要绕过整个符号，必然与电源线交叉。
> 右列避开 strapping 脚 GPIO2 之后可用的是 GPIO0/1/3/4，取 **4/3/1**。约束一条没破：**三个都在 GPIO0~5 内（深睡唤醒要求），且都不是 strapping 脚**。

### 🔴 N2 不是 GND，别接在一起

`VBAT_N`（电芯负）和 `GND`（系统地）之间**隔着 DW01 控制的两颗保护 MOS**（FS8205）。
把它们连起来 = **把保护电路短路掉**，过放/过流/短路保护全部失效。

TP4056 带保护模块的四个端子就是为此分开的：**B+/B− 接电芯，OUT+/OUT− 接负载**。
（不带保护的模块只有 BAT+/BAT−，那种不能用。）

---

## 4. 关键设计说明

### 4.1 三个按键都必须落在 GPIO0~5，且不能用 GPIO2

- **GPIO0~5**：ESP32-C3 只有这几个脚支持**深睡唤醒**。遥控器平时深睡，靠按键唤醒
- **GPIO2 是 strapping 脚**，上电瞬间必须为高。按键按下是拉低的 —— 小孩按着"抬杆"键去拨电源开关，芯片可能进不了正常启动模式
- 避开 GPIO2 后可用的是 GPIO0/1/3/4/5，取 **3/4/5** 三个连号，顺带离 GPIO8/9（另两个 strapping 脚）也远

**按键一律"按下接 GND"，用 C3 内部上拉，不要外部电阻。**

### 4.2 拨动开关必须串在电池和 C3 之间

```
电池 ──► U2 的 B+/B−（充电与保护）
             │
        OUT+/OUT−
             │
        SW4 拨动开关（只断正极）
             │
        U1 的 5V 脚 ──► 板载 LDO ──► 3V3
```

**位置不是随便挑的，它同时解决烧录时的倒灌**：

C3 SuperMini 板上的 Type-C（烧录口）5V 是直通 5V 脚的。如果开关不在这个位置，插着 USB 烧录、电池又接着，USB 的 5V 会顺着 5V 脚倒灌回 U2 的 OUT+ —— 而 **OUT+ 与 B+ 直连**（保护只切负极），等于拿 5V 直接怼电池。DW01 会在 4.28V 跳过充兜底，但那是靠保护救命，不是设计。

开关串在中间之后：**关掉开关 = 电池与 C3 完全断开**，倒灌路径不存在。

> **规矩：烧录前先把拨动开关拨到关。** 充电不受影响 —— 充电走 U2 自己的 Type-C 到 B+/B−，与开关无关。

**进 5V 脚而不是 3V3 脚**：让板载 LDO 稳压。电池 4.2→3.0V 掉到 LDO 压差以下后输出跟着电池走，而 C3 本来就能在 3.0V 工作。

### 4.3 C1 为什么建议加

ESP-NOW 发射瞬间电流会跳到上百 mA，而供电路径上串着电池引线 + 拨动开关 + 排针，都有寄生电感。C3 SuperMini 板上自带的输入电容不一定够，最坏结果就是主机那份文档里写过的同一个症状——**一按遥控器就重启**。

一颗 10µF 0805 陶瓷，成本几分钱，**贴板底面不占高度预算**。
⚠ **不要用电解电容**：φ5×11 的立式电容高 11mm，板面以上只有 6.9mm，直接装不下。

---

## 5. 布局要点（画 PCB 时看这一节）

### 5.1 🔴 C3 的天线端必须悬出板边

SuperMini 的天线在板子一端。天线正下方压着铜箔会严重削弱 ESP-NOW 距离。
**要么让天线端悬出载板边缘，要么天线正下方整片挖空**（无铜、无走线、无地平面）。

主机那边不明显（DevKit 插排母架空 7.5mm），遥控器贴板直焊就非常要命。

### 5.2 轻触开关高度要等板面 z 定了再选

板面 z ≈ 11.1、盖面 z ≈ 22（按目标外壳 68×32×22 算）→ **顶杆要够到 10.9mm 才与盖面齐平**。

主机就是漏了这条：6×6×12 的顶杆差 7.4mm 够不到盖面，最后不得不补两个打印按键帽。
遥控器现在还来得及**直接选对高度**（6×6 有 4.3/5/7/8/9/10/12mm 等档），选不到合适的就同样配打印帽。

**动作力选 100~160gf**，别买 300gf 的——6 岁小孩按不动（这条主机已验证）。

### 5.3 三个按键的间距要按手指定，不是按板子定

顶面三个键，中心距 **≥ 18mm**（主机是 20mm）。φ9 级别的按键帽/按键孔，间距小于 15mm 手指会误触。

### 5.4 其他

| 项 | 要求 |
|---|---|
| U2 的 Type-C | 朝板子一端，对准外壳端面开口 |
| SW4 拨柄 | 同一端面，让开 Type-C |
| 电池焊盘 P1/P2 | 靠近 U2 的 B+/B−，引线短 |
| 板底面 | 只有 C1（0805）和电池，**电池垫在板下**，注意支撑柱高度 |

---

## 6. 校验结果 ✅（2026-08-15）

原理图已连完并保存，用坐标几何重建网表，**8 条网络与 §3 逐条对上**：

```
[C1.2, SW1.2, SW2.2, SW3.2, U1.15, U2.4]   GND
[C1.1, SW4.3, U1.16]                        V5
[SW4.2, U2.1]                               VSYS
[P1.1, U2.2]                                VBAT
[P1.2, U2.3]                                VBAT_N
[SW1.1, U1.13]                              BTN_UP  (GPIO4)
[SW2.1, U1.12]                              BTN_DN  (GPIO3)
[SW3.1, U1.10]                              BTN_RST (GPIO1)
```

**未连接的引脚全部是预期内的**：U1 的 11 个空闲 GPIO、U2 的 IN+/IN−（模块自带 Type-C，不外接）、SW4.1（SPDT 用不到的另一个触点）、SW4.4/5（固定脚）、三个按键的 3/4 脚（与 1/2 脚在开关内部同点）。

**阳性对照（两条都通过）**：

| 假引脚 | 位置 | 结果 |
|---|---|---|
| `FAKE.A` | (5,5)，远离一切 | 落单 ✅ |
| `FAKE.B` | (910,495)，**距 SW1.1 只有 5 个单位** | 掉出 BTN_UP ✅ |

第二条是关键：它证明校验器**真的在判别距离**，而不是把附近的点一律并进去。没有这条，工具失效了也看不出来。

### 方法（照主机那套）

1. 读回所有元件引脚坐标 + 所有导线几何（`getState_Line()` 返回的是**按段展开的扁平数组**，每 4 个数一段）
2. 并查集：每段两端点合并 → 落在任意线段上的点（含 T 型接点）并进去
3. 与 §3 逐条比对
4. ⚠ **必须带阳性对照**，否则工具本身失效了都不知道

### 另加一条：导线有没有压在符号上

网表对 ≠ 图画得对。把每根导线段与每个元件的**引脚包围盒**求交，看有没有线从符号肚子里穿过去。

这次就抓到一处：C1 的 GND 支线原本走 y=300，正好从 SW3（引脚盒 y 270~310）中间穿过。**它不短路**——网表校验已证明 SW3 三个网络都对——但线压在符号上是隐患：以后谁挪一下元件就可能变成真短路。已改走 y=300 → x=860 → 下到主干 y=240 绕开。

> 这条检查很便宜（几十行），而且**是纯几何的、不用看图**。改完记得重跑网表校验，别只跑一个。

> ⚠ `sch_Net.getAllNetsName()` 返回**空**，导线的 `getState_Net()` 也是空 —— 这是主机那次就发现的 API 退化，**网表只能靠坐标几何重建**，不能信 EDA 自己报的网络名。
> ⚠ **网络标识（GND/5V 符号）放不进去**：`sch_PrimitiveComponent.create` 放 netflag 类型必定卡 30 秒超时（EDA 大概率弹了命名框等点击）。本图因此**全部用普通导线连通、零交叉**，不依赖任何网络标识。

---

---

## 6b. PCB ✅（2026-08-15，DRC 零错误）

**板 57 × 33**（x ±28.5，**y −18 … +15**），双层。板框画在 Board Outline 层（11）。
y −18…−15 那条是**纯安装边**，为了给锁紧螺柱腾缺口，见 §6c。

| 位号 | 坐标 (mm) | rot | 说明 |
|---|---|---|---|
| U2 TP4056 | (−13.5, −5.5) | 0 | Type-C 朝 −X，本体前沿距板边 0.5 |
| U1 C3 SuperMini | (16, −5.5) | **270** | 长边沿 x，Type-C 朝 +X 板边，天线端朝 −X。⚠ **外壳 +X 端不开孔**，见 §6c 末 |
| SW4 拨动 | (−23.1, 9.5) | **270** | 🔴 见下 |
| SW1 抬杆 | (−16, 9) | 0 | |
| SW2 落杆 | (2, 9) | 0 | 三键间距 18mm |
| SW3 复位 | (20, 9) | 0 | |
| P1 电池焊盘 | (−7, 9.5) | 0 | |
| C1 10µF | (10, 9.5) | 0 | 顶层，避开板下电池 |

分两条道：**模块道** y −14.5…3.5 放 U2 + U1；**按键道** y 4.5…14.5 放拨动开关、三个按键、电池焊盘。元件两两净距最小 >1mm。

### 🔴 拨动开关的朝向：rot **270** 不是 90

rot 90 时拨柄朝**板内**，装上去根本拨不到。主机的 SW3 用的就是 270（拨柄尖指 −X），这次照抄错了朝向，是用户看图发现的。

⚠ **旋转 180° 会让 1/3 脚对调**（3 脚从 y=11.5 变到 7.5），所以改朝向之后**必须重布**碰到这颗开关的网络，不能只转不管走线。

拨柄尖约在元件原点外 9.4mm → 绝对 x ≈ −32.5。外壳外壁面按 −31.5 设计时，拨柄露出约 1mm，手指拨得动。

### 🔴 U1 朝向：Type-C 必须朝板边（rot 270）

最初放的是 rot 90（天线朝 +X 板边，射频最优），但那样 **Type-C 朝板内、正对着 TP4056 模块，插不进线**。用户指出后改成 **rot 270**：

- **Type-C 朝 +X 板边**，前面无遮挡（当时的打算是外壳 +X 端面开烧录口，改程序不用开壳）
  > ⚠ **这条后来被推翻了**：两个 Type-C 都通到电池，插错口会拿 5V 直接怼电芯。**外壳 +X 端不开孔，烧录靠拆壳拔模块**，见 §6c 末。板上朝向仍保持 rot 270 不变——理由变成"Type-C 朝板边才拔得动模块"。
- 充电口在 −X 端、烧录口在 +X 端，两头分开不会插错
- 天线端转到模块的 −X 侧（x ≈ 4.7…10.5），避让槽跟着挪到 **x 5.5…11，y −11…0**

天线转到板内本来是射频上的让步，但**模块插排母后架空 7.5mm**，离铜箔已经够远，影响不大。

⚠ **转 180° 会把用到的 5 个焊盘全部镜像到另一排**（从 y=+2.12 变成 y=−13.12），所以碰到 U1 的 5 条网络必须全部重布，不能只转朝向。

### 天线避让

**在两排焊盘之间挖了 5.5 × 11 的槽**，天线正下方无 FR4 无铜。

> 焊盘几乎占满模块全长（跨距 17.78 / 本体 22.52），**"让天线悬出板边"这条做不到**——悬出超过 2.4mm 焊盘就掉到板外了。所以改用挖槽。
> ⚠ **电池垫在板底下，别让它压在天线正下方**：电池仓要排在 x −28…+4 那一段。

### 布线

- **三条按键信号手工布顶层**，分车道走（目标 x 越靠右车道越高），零交叉
- **五条电源网络用内置自动布线器**（`autoRouting`），走底层，1.6 秒完成
- 线宽：信号 0.25mm

**DRC 零错误。** 中间修过一处：BTN_RST 的车道原在 y=5.6，距 SW3 的 3 脚焊盘只剩 0.22mm 净距，DRC 报 `TH Pad to Track`，车道下移到 5.2 后通过。

### 连通性验证（独立于 DRC）

读回全部焊盘与走线段做并查集，**8 条网络全部单连通**。

阳性对照：把探针从真实焊盘位置偏移 0.10 / 0.30 / 2.0mm，三档**全部判断开** —— 证明 0.03mm 的判据是严的。

> ⚠ 第一版判据取 0.02mm 时误报过一条（走线端点距焊盘中心 0.01mm，实际稳稳落在焊盘里）。**判据太严会制造假故障，太松会放过真断线**，所以必须配阳性对照来标定。

### 充电指示灯观察窗（rc_top）

**外壳坐标 (−18.7, +2.0)，窗 6 × 4。**（注意是外壳坐标，PCB 坐标是 (−18.7, +0.5)，差 `RC_PCB_DY = 1.5`）

位置不是量的，是**从主机那颗实测值反推**的——两边同一款 28×17 模块、同为 rot 0：

> 主机 LED (−80, 0)、U3 (−74.8, −6) → LED 相对模块中心 **(−5.2, +6)**
> 遥控 U2 在 PCB (−13.5, −5.5) → LED 在 PCB **(−18.7, +0.5)** = 外壳 **(−18.7, +2.0)**

⚠ **窗只能开 6×4，不能照抄主机的 10×6**：SW1 按键的 φ11.5 导向凸台在外壳 (−16, 10.5)，窗放大或往 +Y 挪就会啃进凸台，**凸台缺一块 → 按键帽导向跨度变短 → 按键晃**。现在窗最近点 (−15.7, 4) 到凸台中心 6.51mm，凸台半径 5.75 → 让开 **0.76mm**。自检 `t=90/91`（阳性对照用最初拟的 (−18, 5)，必须啃上）。

### 🔴 充电口开口要按插头塑料头开（2026-08-15 补，主机同病）

外壁面 −31.5 / 内壁面 −29.5 / 板边 −28.5 / U2 本体前沿（座口）−28.0 → **死区 3.5mm**，比主机的 3.27 还大。

Type-C 完全插入时**塑料头前端面基本贴住座口**，所以这 3.5mm 得由塑料头自己钻过去。原来 `RC_USB` 开 **10 × 4.5** 是照金属壳（8.34 × 2.56）开的，用户实测线材塑料头 **11 × 6.5**，过不去 → 插头顶在外壁上，金属壳只进 6.5 − 3.5 = 3.0mm，**接触不上**。

已改为 **12.5 × 8.0**。自检 `t=82/83`（阳性对照：塑料头放大到 14×9 必须被挡住）。

### 板框四角倒 R2 ✅（2026-08-15 补做）

外壳四周是 R3.4 圆角，板子却是直角 → 板角到腔壁只剩 0.34mm。**板四角倒 R2 后升到 1.0mm**（再倒大也没用，这时卡的是直边净距）。CAD 侧 `RC_PCB_CR = 2`，EDA 侧同步改完。

**改法**：读回原板框折线（`pcb_PrimitivePolyline`，图元 `fec1a069811a929e`，层 11），把四个直角各换成 **16 段离散化的 R2 圆弧**，再用 `pcb_PrimitivePolyline.modify(id, {polygon})` 原地改——不用删了重建，图元 ID 不变。

> **为什么不用真圆弧**：多边形数组支持 `ARC` 段，但文档自相矛盾——正文写 `startX startY ARC angle endX endY`，示例却是 `"ARC", 400, 220, 15`（末位才是角度）。这个 API 已经在"自动闭合"上骗过一次，不赌第二次。16 段离散化的最大偏差 **0.0024mm**，比铣边公差 ±0.2mm 低两个数量级。

**改完的验证（不只看 DRC）**：

| 查什么 | 结果 |
|---|---|
| 顶点数 / 闭合 | 85 点，首尾重合 |
| 包围盒 | 仍是 57 × 33（−28.5…28.5 × −18…15）|
| 每个顶点落在直边上或离圆心正好 R=2 | 全部命中，最大偏差 **1.7 nm**（EDA 的 mil 量化）|
| **阳性对照：原来四个直角必须消失** | 四个都查无此点 ✅ |
| 四个螺柱缺口 / 八个圆弧起止点还在 | 全在 |
| 铜箔到板边最小净距（自己算，不靠 DRC）| **0.623mm**，在缺口处；离板边最近的焊盘 1.35mm。倒角削掉的料附近没有任何铜 |
| DRC | 零错误 |

> ⚠ **DRC 改前改后都返回 `true`，这本身不构成证据**。上面那条净距是独立算出来的：把板框折线拆成 84 段，对每个焊盘（减铜箔半径）和每个走线端点（减半线宽）求点到折线的最小距离。

### ⚠ 五条 EDA API 坑（这次新踩）

1. **`pcb_MathPolygon.createPolygon` 不会自动闭合**，尽管文档写"如果首尾不重合将会自动重合"。板框少画了左边那条，**API 全程报成功、`zoomToBoardOutline()` 也返回 true**，是用户看图发现的。**必须显式把首点补回末尾。**
2. **`createPolygon` 只能做闭合形状，不能拿来画走线**（传开放路径直接抛"无法创建多边形图元"）。走线用 `pcb_PrimitiveLine.create(net, layer, x1,y1,x2,y2, width)` 一段一段建。
3. 🔴 **删走线只删 `pcb_PrimitiveLine` 会留下孤儿过孔**。重布之后 DRC 报 `Connection Error`，指着两个不在任何走线上的过孔。删线时必须**连 `pcb_PrimitiveVia` 一起清**。
4. **连通性校验必须分层**。第一版校验器不看层，把底层走线从顶层 SMD 焊盘底下穿过也算连上，**给了假通过**，是 DRC 抓到的。正确模型：节点 =（x, y, 层），同层线段连两端，**直插焊盘（层 12）和过孔才跨层**。
5. 🔴 **`dmt_Project.openProject()` 换不了工程，永远返回 `false`**（`openProject(uuid)` / `openProject(uuid, true)` / 把工程 uuid 传给 `openDocument` 全试过）。`getProjectInfo(uuid)` 倒是能跨工程读到信息，所以不是权限问题。**跨工程只能让人手点开**。同工程内换文档没问题：`dmt_EditorControl.openDocument(docUuid)` 正常，返回 `docUuid@projectUuid`。
   > 顺带：`dmt_Pcb.getAllPcbsInfo()` 只列**当前工程**的 PCB，所以工程没打开就拿不到它的文档 uuid，也就没法绕过这一步。

---

## 6c. 外壳接口与锁紧螺丝（2026-08-15 算完，板框已按此定稿）

### 三处必须露出外壳的特征

| 特征 | 面 | y | z 范围 |
|---|---|---|---|
| U2 充电 Type-C | −X | **−5.5** | 12.7 … 15.9 |
| SW4 拨柄 | −X | **+9.5** | 约 11.5 … 15.5，**拨柄尖 x = −32.5** |
| U1 烧录 Type-C | +X | **−5.5** | **19.6 … 22.8** |

三者高度差很大，因为 U1 插排母后被架空 7.5mm。

### 🔴 长度方向锁死，只能往宽度让

- **−X**：拨柄尖固定在 x=−32.5，外壁面必须落在 −31.5 左右它才露得出来。**内腔不能加长**，加长了拨柄缩回壳里。
- **+X**：USB-C 插头壳长只有 6.5mm，外壁面到座子的距离超过约 2mm 就插不到底。**同样不能加长。**

所以外壳想腾地方**只能加宽**。

### 🔴 U1 的 Type-C 顶到分模线

板面 11.1 → 排母 5.0 + 隔片 2.5 + 模块板 1.0 = 19.6 → USB-C 座顶 **22.8**，而上盖背面原本在 23.0，**开口上方只剩 0.2mm 壁**。内腔加高 1.5mm，外壳 26 → **27.5**。

### 🔴 锁紧螺柱：四个板角一个都不能用

板 57×30 装进 59×32 的内腔只剩 1mm，螺柱必须啃进板子。逐角算下来：

| 板角 | 5×5 缺口会切到 | |
|---|---|---|
| (−28.5,−15) | U2 的 6 脚焊盘 (−25.22,−12.68) | ❌ |
| (+28.5,−15) | U1 下排焊盘 (24.89,−13.12) | ❌ |
| (+28.5,+15) | SW3 焊盘 (23.05,11.25) 擦过 0.45mm | ❌ |
| (−28.5,+15) | 最近 SW4 (−23.1,13.65) | ✅ 唯一 |

**而且 −Y 边的右半段永久不可用** —— U1 那排焊盘压在 y=−13.12、x 7.11…24.89，那一整段边带动不了。

### 解法：板往 −Y 加宽 3mm 做纯安装边

**板最终 57 × 33**（x ±28.5，**y −18 … +15**）。多出来的 y −18…−15 那条是空的安装边，四个缺口开在：

| 缺口 | 位置 | 净距 |
|---|---|---|
| 下左 | x −16.5…−11.5，y −18…−15 | 离走线 10mm ✓ |
| 下右 | x 11.5…16.5，y −18…−15 | 离走线 0.86mm ✓ |
| 上左 | x −10…−5，y 12…15 | 扫描窗口 x −9…−5.5 |
| 上右 | x 8.5…13.5，y 12…15 | 扫描窗口 x 9…13 |

螺柱 φ4.4 中心落在 (−7.5, 14.2)(+11, 14.2)(−14, −17.2)(+14, −17.2)。

> ⚠ **找缺口位置必须按焊盘"铜箔边缘"算，不能按中心。** 第一版扫描用中心距 0.45mm 当判据，选出来的位置 DRC 直接报 `Board Outline to TH Pad` —— THT 焊盘半径约 0.9mm，0.87mm 的中心距实际净距是 0。改成**中心距 ≥1.5mm** 后才对。
> ⚠ 自动布线器把板边当走线通道用了（它当时看到的是光板），所以**改板框之后必须重跑 DRC**，不能假定走线还合法。

### 外壳最终尺寸 **63 × 40 × 26**

🔴 **电池实测 32 × 20 × 4.6**（不是早先文档写的含保护板 7×21×32），薄了 2.4mm。高度链重算：

| 层 | 累计 z |
|---|---|
| 地板 2 + 电池 **4.6** | 6.6 |
| 支撑 0.5 + 板 1.6 | **8.7（板面）** |
| U1 叠高 11.7 | 20.4 |
| 上盖背面 23 / 上盖 3 | **26.0** |

**为什么是 26 不是 24**：24 时上盖背面在 21，而按键帽的 φ11 导向凸台要往下伸 2mm 到 19 —— 而 U1 叠高顶面在 20.4，**凸台会撞在模块上**。凸台位置由 PCB 的按键坐标定死（SW3 在 x=20，正压在 U1 上方），挪不了，只能把腔加高。这条是自检 `t=64` 抓到的，不是算出来的。

### ❌ 不开 U1 的烧录口（2026-08-15 用户拍板）

两个 Type-C 并存的风险：**充电器插错到 C3 那个口**，5V 会顺着 5V 脚 → 拨动开关 → TP4056 的 OUT+，而 OUT+ 与 B+ 直连（保护只切负极）= 直接怼电池。DW01 能在 4.28V 兜住，但那是靠保护救命不是设计。

- **开发板本身烧不了** —— C3 的 USB 口本来就吃 5V
- 想彻底堵死要在开关后串肖特基，0.3V 压降会让电池到 3.3V 就用不了，白扔一截容量
- **改成拆壳拔模块烧录**（排母就是为此装的）

顺带：那个开口原本把外壳顶到 27.5（USB-C 座顶 22.8 差点豁穿分模线），去掉后高度只由电池和叠高决定。

### ~~外壳目标~~（已被上面取代）

板 57 × 30 → 内腔约 59 × 32 → **外壳约 63 × 36 × 26**。

高度链（插排母之后）：

| 层 | 累计 z |
|---|---|
| 地板 2 + 电池 7 | 9 |
| 支撑柱 0.5 + 板 1.6 | **11.1（板面）** |
| U1 叠高 11.7 | 22.8 |
| 留 0.2 + 上盖 3 | **26.0** |

⚠ **26mm 对手持件偏厚。** 想压薄只有一条路：**把电池从板底下挪到板旁边**，能省 7.5mm（降到约 18.5），代价是平面变长（约 89 × 30，更像细长的电视遥控）。这个取舍留到做外壳时定。

---

## 7. 变更记录

| 版本 | 日期 | 说明 |
|---|---|---|
| v1 | 2026-08-15 | 首版。按用户三条决定（无状态灯 / 无电量检测 / 尺寸可动）定案；按键避开 strapping 脚 GPIO2；定死拨动开关在电源链上的位置（顺带解决烧录倒灌）；电池端子改焊盘（KF128 太高装不下）|
| v1.1 | 2026-08-15 | **原理图已建并校验通过**。按键最终落 **GPIO4/3/1**（原计划 3/4/5，因 GPIO5 在符号左侧会导致走线交叉）；补 EDA 选型锁定表与工程 uuid；记录两条 API 退化（网络名读不到、网络标识放不进去）|
| v1.2 | 2026-08-15 | **PCB 完成，DRC 零错误**。板 57×30；封装几何已核（U1 行距 15.24 用户实测确认）；拨动开关朝向更正为 rot 270；天线避让改用挖槽（悬出做不到）；补 §6b 全部 PCB 结论与两条新 API 坑 |
| v1.3 | 2026-08-15 | **U1 改插低背排母**（要反复拔下来改程序，封装不用动）→ 叠高 6.7→**11.7**、外壳 22→**26**、按键必须配打印帽。**U1 转 rot 270 让 Type-C 朝板边**，外壳 +X 端加烧录口，改程序不用开壳；天线避让槽随之挪到 x 5.5…11。补两条新 API 坑（孤儿过孔、连通性校验必须分层）|
| v1.4 | 2026-08-15 | **按三处开口 + 锁紧螺丝重算尺寸链**（§6c）。发现：长度方向被拨柄行程和 USB 插头深度**双向锁死**，只能加宽；U1 的 Type-C 顶到分模线 → 外壳加高到 **27.5**；**四个板角一个都用不了**、−Y 边右半段被 U1 焊盘永久占死 → 板往 −Y **加宽 3mm 做纯安装边**，板 57×30 → **57×33**。外壳定为 **63 × 40 × 27.5**。DRC 重跑零错误 |

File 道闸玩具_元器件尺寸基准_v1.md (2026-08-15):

# 道闸玩具 · 元器件尺寸基准 v1

> **本表是所有物理尺寸的唯一事实源。**
> CAD（`cad/daozha.scad`）**不允许自己定义任何元件尺寸**，只能引用本表。
> 需求书 / 设计方案与本表冲突时，**以本表为准**。

---

## 0. 怎么用这张表

### 没有实物也能填

不一定要等实物到手。以下任一种都可以把 ❓ 转成 📄：

- **发我器件的数据手册 / 规格书 PDF**（尺寸图那几页就够）
- **发我卖家详情页的尺寸图截图**（模块类器件通常只有这个）
- **发我带标注的实物照片**（拿卡尺量的话直接给数字更好）

我逐个读完直接填进表里，并把来源标成 📄。**模块类器件（TP4056/DRV8833/升压/INMP441/DevKit）没有正式手册，卖家尺寸图就是最好的来源**；分立器件（微动开关、轻触开关、拨动开关、端子）一般有正式规格书。

### 数据来源标记

| 标记 | 含义 | CAD 可以依赖吗 |
|---|---|---|
| 📏 | **实测**（卡尺量过实物） | ✅ 可以冻结 |
| 📄 | **数据手册/封装库**有明确标注 | ✅ 可以冻结 |
| 🔒 | **采购已锁定**（选型锁定文档里已定 device uuid） | ✅ 型号可依赖，尺寸仍需 📏/📄 |
| ❓ | **假设值**（按通用规格取，没核实过） | ⚠️ **不可冻结**，CAD 里对应特征算"未冻结" |

**规则**：只要某个特征依赖 ❓ 的数字，这个特征在 CAD 里就是未冻结状态，不能拿去打样。
本表当前状态：**绝大多数还是 ❓**，这就是为什么要先做这张表再改 3D。

### 坐标约定（重要）

历史文档有**两套**坐标，是混乱的一大来源：

| | 长度方向 | 车行方向 | 高度方向 |
|---|---|---|---|
| **设计方案 v2.1** | X | Z | **Y** |
| **CAD / 本表（采用）** | X | Y | **Z** |

**本表和 CAD 统一用后者**：X = 前后（−X 前端面/按键侧，+X 闸杆伸出侧），Y = 车行方向，Z = 高度，Z=0 是底座底面外表面。读设计方案时把它的 Y↔Z 对调。

---

## 1. 机电件

| 项 | 位号 | 型号 | 关键尺寸 (mm) | 安装方式 | CAD 参数 | 来源 |
|---|---|---|---|---|---|---|
| 减速电机 | — | N20 6V 15rpm | 截面 **10(X) × 12(Z)**；减速箱 **9** + 电机 **15** + 尾盖 **1.2** = 机身总长 **25.2** | 端面 2×M1.6 螺孔固定，或矩形隧道夹紧（待定，见下） | `MOT_W/MOT_H/MOT_L` | 📄 卖家尺寸图 |
| ↳ 输出轴 | — | D 形轴 | φ**3.0 (0/−0.03)**，伸出 **10** | 插转毂 D 形孔 | `SHAFT_D` `SHAFT_L` | 📄 |
| ↳ D 面对边 | — | — | **2.45**（φ3 切一刀，平面距轴心 0.95） | 转毂 D 孔靠它传扭矩 | `SHAFT_FLAT` | 📄 实物标注图 |
| ↳ 轴根凸台 | — | — | φ**4**，凸出 **0.7** | 转毂端面必须让开它 | 新增，CAD 里还没有 | 📄 |
| ↳ 安装螺孔 | — | — | **2×M1.6，深 2.1**；以输出轴心为原点，沿 **12mm 边**（装配 Z 向）上下各偏 **4.5**，孔距 **9**；即闸体局部 **(0, 15.5)** 与 **(0, 24.5)** | 见下方支架板 | 新增 | 📄 用户确认 |
| 限位微动开关 | — | **ZIPPY DF-P1S-1E-M-Z**（正式型号 1000100978，直压柄 13mm，焊线脚）| 本体 **12.70 × 6.60 × 5.80**；安装孔 **φ2.20 @ 间距 6.50**；端子焊线脚脚距 5.08 厚 0.60<br>**FP Max 10.6 / OP 8.4±0.8 / PT Max 3.0 / OT Min 0.6 / MD Max 0.8**<br>OF Max 56gf / RF Min 8gf；SPDT；0.1A 30VDC；寿命 100 万次；接触电阻 Max 100mΩ | 2 颗 M2 盘头穿本体 φ2.2 孔，拧进开关托板的**径向长圆孔**；引线焊在焊片上 | `SW_HOLE_R` `SW_SPACING` | 📄 **ZIPPY 官方规格书** 全部确定 |
| 按键轻触开关 | SW1/SW2 | 6×6×**12** + **打印按键帽** | 本体 6.0×6.0，**总高 12 = 底座 3.5 + 开关柄 8.5**（不含引脚）；THT 4 脚，脚距 4.5；**行程 0.25**；额定 DC12V 0.6A；动作力 **70~300gf（系列范围，需指定 100~160gf）**；顶杆**锥台 φ3(根)→φ2.5(尖)** 📄 | 焊在承载底板；**顶杆够不到上盖，必须加按键帽**（见下） | `BTN_D` | 📄 规格书 / ❓ 顶杆直径、动作力档位 |
| 总电源拨动开关 | SW3 | **SK12D07VG7**（两档 SPDT / 卧式侧拨）| 本体 **8.7 × 4.4**，含引脚总高 7.2~7.3；信号脚 3 个 **间距 2.0**（0/2/4），两端另有固定脚，总跨 **8.3**；脚厚 0.4/0.5；拨柄宽 **2**、行程 **2**；拨柄高 H **系列 2~12 可选**，本款 =7 | 焊在承载底板，拨柄侧出对准前端面开口 | `PSW_W/PSW_H/PSW_Y` | 📄 卖家尺寸图 / ❓ H 的基准面 |
| 有源蜂鸣器 | LS1 | φ9×5.5 3V 🔒 | φ**9.0** × 高 **5.5**，脚距 **5.0** | 焊在承载底板 | — | 📄 封装 `BUZ-TH_BD9.0-P5.00` |

### ✅ M1.6 孔位已确定

**(x=0, z=±4.5)**，孔距 9，沿端面 12mm 那条边分布，不是对角线。孔心距端面上下边 1.5mm——钢件上 M1.6 攻丝可行。

至此 **N20 全部参数转 📄，无遗留项**。

支架板可行性核算：

| | |
|---|---|
| 孔在 r=4.5，M1.6 头 φ3.2 | 支架需覆盖到 r=6.1，取 **r=7** |
| 支架板 y = −12.5…−10.5（2mm 厚） | 凸轮在 y=−19…−13 → **让开 0.5mm** ✓ |
| 支架 r≤7 vs 微动开关 r≥9.85 | **不干涉** ✓ |
| 中心 | 开 φ4.5 让开 φ4×0.7 轴根凸台 |

<details><summary>（原"坐标仍差一个数"的分析，保留备查）</summary>

已知：两孔关于端面中心对称，在与十字螺丝相反的那条对角线上。
**但"对称"只给出一个方程、两个未知数**——设孔心坐标 (±x, ±y)，若中心距为 9 则 x² + y² = 4.5² = 20.25，x 可以在下面这条带上任意取：

| x | y | 到左右边 | 到上下边 | |
|---|---|---|---|---|
| 0.0 | 4.50 | 5.00 | **1.50** | 边距不足 |
| 1.5 | 4.24 | 3.50 | 1.76 | 可行 |
| 2.5 | 3.74 | 2.50 | 2.26 | 可行 |
| 3.4 | 2.95 | 1.60 | 3.05 | 可行 |
| 3.8 | 2.41 | **1.20** | 3.59 | 边距不足 |

（边距按 M1.6 攻丝孔中心距板边 ≥1.6mm 估）
可行区间跨度约 2mm，而 M1.6 过孔要求定位精度 ±0.3mm，**不够用**。

另外还有一层不确定：**那个"9"到底是不是孔距**。两张图里的 9 都可能是"减速箱长度 9mm"——第一张图明确标了减速箱长 9，第二张照片的 9MM 箭头也是沿机身方向的。

结果证明那个"9"确实是孔距，且两孔在 12mm 边的中线上（x=0）。

</details>

### 🔴 **推导支架装配顺序时发现：转毂根本装不进去**

| | |
|---|---|
| 左壳 −Y 壁上的轴颈孔 | **φ8.5** |
| 转毂夹杆臂（壁外，y=−35…−24） | **36 × 14** |
| 转毂凸轮（壁内，y=−19…−13） | **φ12~φ18** |

转毂是**一整件**，两端都远大于 φ8.5，**穿不过这个孔**。而闸体分模面在 y=0，这道壁（y=−23…−21）整个属于左壳，**拆开左右壳也分不开它**。

README 装配顺序第 3 步写的"轴颈穿左壳 φ8 孔"，物理上做不到。

**这是布尔自检抓不到的一类问题**——`t=16` 早就验过转毂在最终位置不干涉闸体，但"能不能走到那个位置"是装配路径问题，静态求交测不出来。

### ✅ 最终解法：拆的是**凸轮**，不是臂

**先澄清**：转毂拆件与电机固定方式**无关**，纯粹是壁孔 φ8.5 卡住了 φ18.6 的凸轮和 36×14 的臂。电机怎么固定都改变不了。

但拆在哪里可以选，而**拆凸轮远优于拆臂**：

| | 拆臂（原案） | **拆凸轮（采用）** |
|---|---|---|
| 分件处受力 | 闸杆全部弯矩 + 电机扭矩 | **几乎不受力**，凸轮只负责拨开关 |
| 第二个零件 | 带插槽的夹杆臂，复杂 | **一个简单圆盘** |
| 传扭矩方式 | 需 D 形柱 + 顶丝 | 一颗顶丝即可 |

**最终结构**：

| 零件 | 内容 |
|---|---|
| `hub`（主体，**一整件**）| 夹杆臂 + φ7.5 轴（穿壁孔并伸进腔内）+ 末端电机 D 形孔 |
| `cam`（新增，简单圆盘）| φ18.6 × 厚 6，中心 φ7.6 孔 + 顶丝 |

闸杆的弯矩和电机扭矩**全部走主体这一整件**，符合"能整体就整体"的原则。

**⚠ 轴承长度要补强**：壁只有 2mm 厚，φ8.5 孔的轴承长度就只有 2mm，而闸杆是从壁外悬伸的。**在壁的内侧加一圈 φ12 × 长 4 的凸台**，把轴承长度做到 6mm。这是原设计就有的隐患（不是这次拆件带来的）。

### ✅ 电机确认：只靠矩形隧道夹紧，不加支架板

矩形截面本身防转，尾挡筋定轴向，右壳合上即夹紧。**不用 M1.6 螺钉**，省掉支架板，`MOT_Y0` 回到 **−12.5**。
端面那两个 M1.6 孔留着，日后若发现松动可以再加支架加固。

### ⚠ 轻触开关：12mm 也够不到上盖，必须加按键帽

板面 z=5.6，上盖背面 **19**、顶面 **22**。

| 规格 | 顶杆尖 z | 结果 |
|---|---|---|
| 6×6×5（设计方案原值） | 10.6 | 差 **8.4mm** ❌ |
| 6×6×12 | 17.6 | **差 1.4mm** ❌ |
| 6×6×16 | 21.6 | 低于盖面 0.4mm |
| 6×6×17 | 22.6 | 高出盖面 0.6mm |
| 要与盖面齐平所需 | — | **16.4mm** |

**根因**：v2.5 为塞下低背排母把 `BASE_H` 从 20 加到 22，天花板从 17 抬到 19，原本刚好探出 0.6mm 的 12mm 顶杆就差了 1.4mm。

**结论：用 6×6×12 + 打印按键帽**，理由不只是补高度——顶杆只有 φ3.5，陷在 φ6.5 孔里，**6~10 岁的手指根本按不舒服**。就算换 6×6×17 让顶杆探出 0.6mm，按的也是个 φ3.5 的小柱子，硌手。

**按键帽 + 上盖开孔（第二版：帽子要露出来）**

第一版让帽顶与盖面齐平，等于没有按键——手指摸不到边界，也没有按下去的行程感。改成**露出 2.5mm、按压面加大到 φ8.5**：

上盖那边改两处：

| 项 | 原 | 新 |
|---|---|---|
| 按键通孔 | φ6.5 | **φ9** |
| 背面沉孔 | 无 | **φ12.5 × 深 1.5**（导向 + 挡住法兰） |

按键帽（新增打印件 ×2）：

> 🔴 **下表是 `BASE_H = 22` 时算的，已被 CAD v3.0 取代**（底座加高到 25，盖面从 22 变 25）。
> **实建值见 `cad/daozha.scad` 的 `CAP_*` 参数**，这里只保留推导过程备查。
> 实建摘要：帽总高 **13.2**（16.8 → 30），法兰 φ12 × **3.0**（z 20.5…23.5），柄 φ8.5 × 6.5（z 23.5…30，露出盖面 5.0），底部盲孔 φ3.2 × 1.0。
> 上盖那边：通孔 φ9、背面沉孔 φ12.5 **总深 4.0**（面板里 1.5 + 新增的 φ14×2.5 导向凸台）。
>
> **法兰厚度是被"按不按得动"卡住的**：帽子能下压的距离 = 沉孔深 4.0 − 法兰厚，
> 而按下去要走 0.2（预留浮动，免得静止时预压开关）+ 0.25（开关行程）= **0.45mm**。
> 法兰取 3.5 就只剩 0.5 可压，余量 0.05mm —— 打印公差 ±0.15 就能让法兰先坐死在沉孔底上，**开关根本压不到**。所以取 **3.0**，余量 0.55mm。

| 段 | 尺寸 | z 范围 |
|---|---|---|
| 法兰 | φ**12** × **2.7** | 17.8 … 20.5（顶面顶住沉孔顶，靠它定位兼防脱） |
| 柄 | φ**8.5** × **6.5** | 20.5 … 27.0（穿通孔，**露出盖面 5.0mm**） |
| 底部盲孔 | **φ3.2**，深约 1.0 | 套住顶杆。顶杆是**下大上小的锥台，φ3→φ2.5**，盲孔取 φ3.2 松套住顶端即可（帽子由上盖孔导向，不靠顶杆定位）|

帽总高 **9.2mm**。

- **按压面 φ8.5**，比原来的 φ6 大一圈，6~10 岁的手指按着舒服
- **防脱**：法兰 φ12 > 通孔 φ9，拔不出去
- **不旷（上下）**：开关弹簧把帽子顶到沉孔顶面定位，留 0.2mm 浮动免得预压住开关；行程 0.25mm 照常
- 两键中心距 20mm，沉孔 φ12.5 → 间隙 7.5mm ✓；法兰跨 y=4~16，止口环内缘 18.75 ✓ 不干涉

**⚠ 露出 5mm 的代价：侧向会晃。** 上下两个支撑点（法兰底 z=17.8、通孔顶 z=22）跨距只有 4.2mm，而帽顶在 27，悬出很长：

| 配合间隙 | 帽顶侧向晃动 |
|---|---|
| 0.5mm（FDM 常规） | ≈ **1.10mm** |
| 0.4mm | ≈ 0.88mm |
| 0.3mm（树脂打印可行） | ≈ 0.66mm |
| 参考：露出 2.5mm 时 | ≈ 0.64mm |

按键帽零件小，**建议和转毂一起用树脂打**，间隙做到 0.3mm，晃动约 0.66mm——和露出 2.5mm 用 FDM 的效果相当。

另一个隐患：帽子越高，**偏心按压**产生的倾覆力矩越大，有可能卡在孔里按不动。间隙做小反而更容易卡，所以 0.3mm 是下限，别再小。

若实测手感还是晃，有两条补救路：① 上盖背面加一圈 φ14×1.5 的凸台把沉孔加深到 3mm，跨距变 5.7mm；② 露出量退回 3.5mm。

露出量是可调参数，只改柄长、法兰不变。

**装配注意**：法兰比通孔大，按键帽必须在扣上盖**之前**从背面放进沉孔。
两个帽子可以打成不同颜色区分抬杆/落杆。

**动作力要指定**：规格书写的 70~300gf 是整个系列的范围。给儿童玩具选 **100~160gf**，300gf 对 6 岁孩子太硬。

### ✅ 型号选定：**ZIPPY DF-PIS-1E-M-Z**（对比 MG1 后改选）

两者是同一种标准小型微动开关的不同品牌，**本体尺寸和安装孔几乎完全一样**（12.7~12.8 × 6.55~6.60 × 5.80，孔距 6.5、孔径 φ2.2），所以结构上可互换。差别在这几处：

| | MG1-R10P40 | **ZIPPY DF-PIS-1E-M-Z** |
|---|---|---|
| 压柄 | 圆弧 10mm | 直杆 13mm |
| 行程 | 1.3mm | **2.2mm** |
| 操作力 | 40gf | 56gf |
| 额定电流 | 1A | 0.1A |
| **端子** | 直插脚（PCB 针） | **焊线脚（带孔焊片）** ✅ |
| 寿命 | 未标注 | **1 百万次** |

**决定性因素是端子形式。** 限位开关装在闸体内的托板上，**用飞线接到底板 J2**，不是焊在 PCB 上。直插脚是给 PCB 用的——3.5mm 长的细针上挂飞线，根部容易疲劳断。焊线脚是带孔的焊片，线穿过去再焊，这才是限位开关的标准接法。

**额定 0.1A 够不够**：NC 接法进 GPIO 内部上拉，回路电流 ≈ 3.3V / 45kΩ = **0.073mA**，0.1A 有一千多倍余量。顺带一提，专为小电流设计的开关在这种"干电路"下的接触可靠性通常**好于**大电流银触点（不易积氧化膜）——不过触点材质建议向卖家确认。

**直杆压柄不再是问题**：我之前说圆弧优于直杆，前提是凸轮有台阶。而凸轮**无论选哪款都必须加过渡斜坡**（见下），加了斜坡以后直杆完全够用——工业上大量限位开关就是直杆配凸轮。

**代价**：行程 2.2mm 比 1.3mm 大，凸轮升程要相应做到 2.9mm，凸起半径 r=8.9，与开关本体内面（r≈9.8）只剩 **0.9mm** 间隙（选 MG1 则有 1.85mm）。这个间隙偏紧但可行，装配时要注意。

<details><summary>原 MG1 选型分析（保留备查）</summary>

### MG1 系列六款对比

| # | 型号 | 压柄 | 行程 | 操作力 | 判定 |
|---|---|---|---|---|---|
| 1 | MG1-0P110 | 无杆 2.9 | **0.3** | 110gf | ❌ **行程只有 0.3mm**，吸收不了凸轮升程，会被压毁 |
| 2 | MG1-11.5P35 | 直杆 11.5 | 1.1 | 35gf | 可用，但直杆尖端会啃凸轮上升沿 |
| 3 | MG1-13.5P30 | 直杆 13.5 | 1.6 | 30gf | 可用（**规格书标注的就是这一款**，尺寸最全）；直杆同上 |
| 4 | **MG1-R10P40** | **圆弧 10** | **1.3** | **40gf** | ✅ **推荐** |
| 5 | MG1-R15P25 | 圆弧 14.7 | 1.7 | 25gf | 好用但杠杆最长，径向包络最大，而这里空间只剩 1.1mm |
| 6 | MG1-S13P40 | 滚轮 13 | 1.3 | 35gf | ❌ 滚轮多占高度，低速小力用不上，空间不允许 |

1 号无杆款行程只有 0.3mm，**正是设计方案原本写的那种**，实锤不可用。6 号滚轮多占高度，低速小力用不上。

</details>

### 🔴 官方规格书推翻了我定的凸轮升程

卖家表写的"行程 2.2"是 **FP−OP 的典型值**（10.6−8.4）。但官方规格书给的是 **Pre-travel Max 3.0mm** —— 最坏批次要压满 3.0mm 才保证动作。

**我原设 `CAM_RISE` = 2.2 + 0.7 = 2.9mm，低于 PT Max，最坏批次可能压不动开关。**

重定 **`CAM_RISE` = 3.3mm**（凸起 r=9.3，`CAM_LOBE_D` = 18.6）：

| 校核 | |
|---|---|
| PT 取最坏 3.0 | 超行程用掉 0.3（规格保证 Min 0.6）✅ |
| PT 取最好 1.4 | 杠杆下压 3.3，距贴死本体还有 0.7 ✅ 不会压毁 |
| 杠杆总可压行程 = FP − 本体高 | 4.0mm |

**教训**：卖家表的"行程"是典型值，官方规格书的 **PT Max** 才是设计依据。差 0.8mm，足以让一批开关全部失效。

### ⚠ 开关安装孔要改成径向长圆孔

按 FP=10.6 算：

| | |
|---|---|
| `SW_HOLE_R` | 6 + 10.6 − 2.0 = **14.6**（原按 FP=10.4 估的 14.4）|
| 本体内面 r=10.0 vs 凸起 r=9.3 | 间隙 **0.7mm** |
| 插脚最外 r=20.1 vs 闸体内壁 21 | 余 **0.9mm** |

**规格书只给了 FP 的 Max，没给 Min。** 若实物 FP 偏小，本体会更靠近轴心，那 0.7mm 间隙就会变成撞上凸起。

**处置：托板的安装孔做成径向长圆孔（φ2.2 宽 × 长 5，即 ±1.5mm 可调）**，装配时把开关滑到"凸起刚好压下、基圆刚好释放"的位置再拧紧。这本来就是限位开关在机床上的标准装法，也顺带吸收打印公差。
2. **凸起两端必须加过渡斜坡**。现在 `rotate_extrude` 出来的是**直上直下的台阶**——3mm 高的垂直墙，杠杆撞上去只会卡死不会骑上去。要在凸起两侧各加 15~20° 的斜坡。

### ✅ 限位开关必须选**带簧片杠杆**的（不是无杠杆直动式）

设计方案 v2.1 原本写的是"微动开关（短柄**无杠杆**）"，**这是错的**，行程量级差了 6 倍：

| | 行程 |
|---|---|
| 凸轮升程（基圆 r6 → 凸起 r9） | **3.0mm** |
| 无杠杆直动柱塞：自由行程 ~0.3 + 超行程 ~0.2 | **约 0.5mm** |
| 带簧片杠杆：杠杆尖端总行程 | **4~6mm** ✅ |

直动式吸收不了 3mm，凸轮转过来会直接把柱塞压毁。杠杆还顺带解决两件事：**超行程顺应性**（吸收打印公差 ±0.15、转毂径向间隙、凸轮偏心）和**安装位置容差**（装偏 ±0.5mm 仍能可靠动作）。

不建议反过来"把凸轮升程降到 0.5mm 去迁就直动式"——FDM/树脂公差 ±0.15mm 加上转毂间隙，0.5mm 升程的触发点根本不可重复。

**不要选滚轮杠杆**：滚轮会多占约 4mm 高度，而这里凸轮转速极低、力也小，簧片直接滑就够。

### ⚠ 连带发现：`SW_HOLE_R` = 12.5 太小，而且托板必须重做

按 KW12 本体径向宽 10.2mm、安装孔居中估算：

| | 值 |
|---|---|
| 本体内缘半径 = 12.5 − 10.2/2 | **7.4** |
| 凸轮凸起半径 | **9.0** |
| 结论 | **开关本体会撞凸轮** |
| 让开凸轮（留 1mm）所需 | `SW_HOLE_R ≥` **15.1** |
| 但托板底面 `= PIV_Z − SW_HOLE_R − 5 ≥ 闸体地板 2` 要求 | `SW_HOLE_R ≤` **13.0** |

**两个约束打架**。`switch_plate` 现在是个 `2·R+10` 见方的整块板，R 一大就从闸体地板捅出去。解法是把托板从"一整块方板"改成**只在两个开关位置各留一块小安装台**，去掉中间和下方无用的料——那样 `SW_HOLE_R` 就不再受托板外形限制。

**按 MG1 实际尺寸重算的结果**：

| | 值 |
|---|---|
| 杠杆尖（自由态贴基圆） | r = 6.00 |
| 本体内面 = 6 + (FP − 本体高) | r = **9.85** |
| 本体外面 = +6.55 | r = **16.40** |
| 安装孔（距本体底边 ~2） | r = **14.4** ← `SW_HOLE_R` |
| 插脚最外端 | r = **19.90** |
| 闸体内壁 | r = 21.0 → **余量仅 1.1mm** |

`SW_HOLE_R` **12.5 → 14.4**，`SW_SPACING` **9.5 → 6.5**。
托板底面 `= PIV_Z − 14.4 − 5 = 0.6`，仍低于闸体地板 2 → **托板必须从整块方板改成两块独立安装台**。

### ✅ N20 有安装孔——固定方式可以改了

减速箱端面有 **2×M1.6 深 2.1** 的螺孔。我之前说"N20 机身没有安装孔"是**错的**（那是 Pololu micro metal gearmotor 的情况）。这意味着可以从"靠合壳摩擦夹紧"改成**螺丝硬固定**，可靠性高一个档次。

但有个几何约束要先解开：端面固定需要一块贴着减速箱端面的支架板，而**凸轮占 y=−19…−13**，支架板会跟它撞。用实测数据重新排一遍轴向：

| | 值 |
|---|---|
| 支架板厚 | 2mm，位于 y = −12.5…−10.5（让开凸轮 0.5mm） |
| 减速箱端面 | y = **−10.5** |
| 轴（10mm）| y = −20.5 … −10.5 |
| 转毂咬合 | 转毂料在 y −24…−13 → **咬合 7.5mm** ✓ |
| 机身尾端 | −10.5 + 25.2 = **+14.7**，离 +Y 内壁(21) 还有 6.3mm ✓ |

**可行**。但螺丝要从凸轮那一侧往 +Y 拧进端面，装配时得在合壳前完成。等孔位确认后我再决定支架板做成壳体一体的还是单独一片。

### ⚠ 实测值 vs CAD 现值的差异

| 项 | CAD v2.6 现值 | 图纸实测 | 影响 |
|---|---|---|---|
| 轴伸出长度 | 9 | **10** | 孔深由 `MOT_Y0 − SHAFT_L` 反推，现在轴会比孔底深 0.5mm **顶死**。改参数即自动修正 |
| 机身总长 | 26 | **25.2** | 尾挡筋位置随 `MOT_L` 自动跟随，无碍 |
| 轴根凸台 | 无 | **φ4×0.7** | CAD 里没建，需补让位 |
| D 面对边 | 2.5（假设） | **2.45** | 平面距轴心 1.0→**0.95**，`FLAT_OFF` 由 1.15 变 **1.10** |
| 安装孔 | 无 | **2×M1.6↓2.1** | 固定方式可升级 |

### ✅ 拨动开关改选 SK12D07VG7（方向问题解决）

原选型 SS12D00G3 是**拨柄朝上**的立式开关，装在底板上拨柄指 +Z，而总电源开口在**前端面（−X）**，方向对不上。改用**卧式侧拨**的 SK12D07VG7，拨柄平行 PCB 面伸出，正对前端面 ✅

**高度对位良好**：本体 4.4 高，板面 z=5.6 → 占 z **5.6~10.0**；前端面开口 z **6~10**，基本重合，不用改开口高度。

**拨柄高度 H 可选 2~12，这是个可利用的自由度**——不用迁就现成规格，按结构反推该买哪个：

| H | 本体前面须落在 | 相对板边 (−71) |
|---|---|---|
| 5 | x = −71.0 | 与板边齐平 |
| 6 | x = −70.0 | 缩进板内 1.0 |
| **7** | x = **−69.0** | **缩进板内 2.0** ✅ |
| 8 | x = −68.0 | 缩进板内 3.0 |

（判据：拨柄尖要停在 x≈−76，即外壁面 −75 再露 1mm，手指才拨得动）

**H=7 可用**，对应本体前面缩在板边内 2mm——留了余量，也不用像 TP4056 那样悬出板边。等 PCB 布局时按这个定位。

> 🔴 **上面这张表是按老底座算的，坐标全部作废（2026-08-15）。**
> 表里的"板边 −71 / 外壁面 −75"对应的是底座还没放大的时候；底座改成 **183×73** 之后外壁面变成 **−91.5**，
> **但没人回头重算这张表**，于是 H=7 一路沿用到 PCB 定稿。实际结果：SW3 在 x=−82.6 时拨柄尖 −92.01，
> **只露 0.51mm，连这张表自己写的 1mm 判据都不满足**。
> **判据本身仍然有效，作废的只是坐标。** 因为物料已买齐（H 换不了），改成**把 SW3 在 PCB 上往 −X 挪 1.5mm**：
> 拨柄尖 → **−93.51，露出 2.01mm ✅**，焊盘到板边仍有 3.9mm。自检 `t=84/85` 钉死这条。

**⚠ 原来的"H 基准面"问题已绕开，不再阻塞。**

我当时想问的是：规格里"拨柄高 7mm"是从**本体侧面**量到拨柄尖，还是从 **PCB 面**量起——因为我想用公式反推本体该放在哪个 x。

但这个数其实不必知道。把要求改成**位置约束**就行：

> **拨柄尖端最终要落在 x ≈ −76**（外壁面 −75 再露 1mm，手指才拨得动）

PCB 布局时拿实物比一下，把开关本体放到满足这条的位置即可。结构这边只要保证前端面开口够大（现为 y 11…19 × z 6…10），怎么放是 PCB 的事。**这条从待确认清单里划掉。**

### 🔴 引脚间距变了，EDA 封装必须换

| | SS12D00G3 | SK12D07VG7 |
|---|---|---|
| 信号脚间距 | 2.54mm | **2.0mm** |
| 脚数 | 3（SPDT） | 3（SPDT）+ 2 固定脚 |

**原理图的网络不用改**（都是 SPDT 三脚），但**封装要换、PCB 焊盘位置全变**。这是继 J3（麦克风 2.0→2.54）之后**第二个要改封装**的器件——转 PCB 之前必须先在 EDA 里换掉。

---

## 2. 电子模块

| 项 | 位号 | 型号 | 关键尺寸 (mm) | 叠高（板面以上） | 来源 |
|---|---|---|---|---|---|
| 主控 | U1 | ESP32-S3-DevKitC-1 **N16R8【向下焊】Type-C** 🔒 | **外形 63.611 × 27.94**；**两排排针孔中心距 25.4**（=1.0″，正好落 0.1″ 栅格）；22 脚/排 P2.54；PCB 1.57，WROOM-1 模组高 3.1 | 插低背排母 | 📄 卖家尺寸图**已复核** |

> 🔴 **系统库封装的行距是错的（2026-08-14 发现）**：`CONN-TH_ESP32-S3-DEVKITC-1U-N8` 两排焊盘间距只有 **22.86mm**，比实际窄 2.54mm，**照它打样 DevKit 插不进去**。
> 尺寸图上 25.400 与 27.940 是两个不同标注——**25.4 是排针孔中心距，27.94 才是板宽**。几何也自洽：27.94 配 25.4 → 每排距板边 1.27mm，排针本体正好与板边齐平。
> 已复制到个人库改为 `CONN-TH_ESP32-S3-DEVKITC-1-N16R8_S25.4`（44 焊盘 X 从 ±11.43 → **±12.7**），并新建器件 `ESP32-S3-DevKitC-1-N16R8-行距25.4`。**这条从 README §还没定的 里划掉。**
| 电机驱动 | U2 | DRV8833 红板（替代 TB6612，排针已焊好）| **18.1 × 21.1 × 高 ≈5**（无高电容）；**2 排 × 8 脚**，排间距 **15**（用户实测；画封装建议用椭圆焊盘吸收 15 / 15.24 的差异）；VM 2.7~10.8V，单 H 桥 1.5A | **可插低背 5.0 排母**（叠高 12.5 < 净空 13.4）| 📄 卖家图 + 用户确认 / ❓ 排间距 |
| 升压 | U4 | **MT3608**（改选，替下 SX1308）| **37 × 17 × 高 7**（📄 卖家尺寸图，**不是 36**）；重 4.39g；4 焊盘在四角，**VIN± 一端、OUT± 另一端，两个正极在同一条长边**（📄 实物图确认）；**孔中心距 = 长边方向 30 × 短边方向 7**（📏 实测）；孔 φ1.651、焊盘 4×4；输入 2~15V / 输出 >5~28V 可调 / ≤2A / 效率 >93% | 平放直焊，**摊在明面**（方案 A），电位器随时可调 | 新增 | 📄 + 📏 **全部确定** |
| 充电保护 | U3 | TP4056 Type-C 模块 **带保护**（TP4056 + DW01 + FS8205）| **28 × 17**（卖家注明手工测量误差 0.5~1mm）；Type-C 在 28mm 边的一端；出厂 Rprog=1.2k → 1000mA；过放保护 2.5V | **必须贴板直焊**；Type-C 座顶 z≈10.4。🔴 **前端面开口要按插头塑料头（实测 11×6.5）开，不是按金属壳（8.34×2.56）开** —— 原来的 10×5 塑料头过不去，插头会顶在外壁上只进一半。现为 **12.5×8.0**，见机械约束 §287 | 📄 卖家图 + 用户实测插头 |
| 麦克风 | — | INMP441 模块（**不焊排针**版）| **圆板 φ14 × 厚 1**；6 个焊盘 **孔径 φ1、间距 2.0**；SCK/WS/SD/L-R/VDD/GND | 固定在**闸体**前面板内侧，**焊飞线**下到底板 J3（L/R 就近接 GND，实走 5 根线）| 新增 `MIC_*` | 📄 卖家尺寸图 |
| 遥控器主控 | — | ESP32-C3 SuperMini（黑色）| **22.52 × 18**；4M Flash；板载 LED 在 GPIO8（**不用，无状态灯**）| 见下方叠高分析 | 📄 卖家图 |

### 🔴 遥控器内腔核算：60×30×20 装不下，目标改 68 × 32 × 22

用户 2026-08-15 拍板：**外壳尺寸可以动，优先保证装得进去**。按实测尺寸算一遍：

**高度方向**（这一维最紧，决定外壳高）：

| 层 | 厚度 | 累计 z |
|---|---|---|
| 底壳地板 | 2 | 2 |
| 502030 电池（含保护板）| 7 | 9 |
| 载板支撑柱净高 | 0.5 | 9.5 |
| 载板 PCB | 1.6 | **11.1（板面）** |
| C3 SuperMini 叠高：排针塑料隔片 **2.5** + 模块板 1.0 + **USB-C 座 3.2** | 6.7 | **17.8** |
| 上盖背面留 0.2 余量 | | 18.0 |
| 上盖 | 3 | **21.0** |

→ 外壳高取 **22**（现在是 20，差 2）。

> **省 2.5mm 的办法**：买**不带排针**的 SuperMini 贴板直焊（像主机的 TP4056/MT3608 那样），叠高降到 4.2，外壳高能回到 20。买之前确认板边是不是半孔（castellated）。
> ⚠ 最高的不是芯片是 **USB-C 座（3.2）**。这个口是烧录用的，留在壳内。

**平面方向**（按占用率反推，主机的经验是 **50~55% 好布、71% 布不通**）：

| 器件 | 占地 |
|---|---|
| C3 SuperMini 22.52 × 18 | 405 |
| TP4056 **28 × 17** | 476 |
| 轻触开关 6×6 ×3 | 108 |
| SK12D07VG7 8.7 × 4.4 | 38 |
| **合计** | **1027 mm²** |

原内腔 56 × 26 = 1456 mm² → 占用率 **71%**，正是主机布不通的那个数。
遥控器的网络比主机少得多（就是电源 + 3 根按键线 + GND），可以放宽到 ~57%：
内腔 **64 × 28** = 1792 mm² → 外壳 **68 × 32**。

**电池不占板面积**（垫在载板底下），但它的 32 × 21 要落在内腔里 ✓ 64×28 装得下。

> ⚠ **这是目标值，不是定稿值。** 最终尺寸以 PCB 布局定稿反推 —— 这就是主机那条"结构让路给 PCB"。先给目标是为了让画 PCB 的时候心里有数，不至于画完发现装不下再返工。

### ⚠ 画遥控器 PCB 时必须留的两条

1. **C3 的天线端必须悬出载板边缘**，或者至少天线正下方整片挖空、无铜无走线。SuperMini 的天线在板子一端，底下压着铜箔会严重削弱 ESP-NOW 的距离。这条主机那边不明显（DevKit 插排母架空 7.5mm），遥控器要是贴板直焊就非常要命。
2. **三个轻触开关的高度要等板面高度定了再选。** 板面 11.1、盖面 22 → 顶杆要够到 10.9mm 才齐平。主机就是没算这条，最后不得不补按键帽（6×6×12 顶杆差 7.4mm 够不到）。遥控器现在还来得及选对高度，选不到就同样配打印帽。

### ⚠ 排母必须买低背 5.0mm

叠高是**四层**，别漏掉第二层：

```
排母本体            5.0（低背）或 8.5（标准）
DevKit 排针塑料隔片  2.5   ← 公排针插进排母后, 隔片坐在排母顶面
DevKit PCB          1.57
WROOM-1 模组        3.1
```

板面以上净空只有 **13.4mm**。标准 8.5 排母 → 15.67mm，**超 2.3mm 装不进**；低背 5.0 → 12.17mm，余 1.2mm。
加高底座救不了：开关托板底面 `PIV_Z − 17.5` 必须高于闸体地板，`PIV_Z ≥ 19.5`，而转轴离地 42 锁定 → `BASE_H ≤ 22.5`，净空上限 13.9。

### ✅ TP4056 模块符合要求，但有两处要处理

**带保护版确认无误**：模块上 **B+/B−（接电池）与 OUT+/OUT−（接负载）分开成四个端子**，这就是带保护的标志（不带保护的只有 BAT+/BAT−）。参数里「电池过放保护 2.5V」也佐证了 —— 那是 DW01 的阈值，TP4056 自身没有这个功能。

> **DW01 + FS8205 是什么**：TP4056 只是充电管理 IC，管"怎么充"（恒流→恒压→截止），**不带电池保护**。DW01 是保护 IC 负责**判断**（过充/过放/过流/短路），FS8205 是双 N 沟道 MOSFET，是 DW01 的**执行开关**。两者配合才构成完整保护电路。

#### ⚠ 1. 充电电流要改小 —— 理由是发热，不是电池限值

电池 2000mAh 允许 0.5C = 1000mA，模块出厂正好 1000mA，**看似正好**。但密闭塑料盒里的 SOP-8 无散热：

| 电流 | 耗散(Vbat=3.0V 起充) | 耗散(3.7V) | 充满约 |
|---|---|---|---|
| 1.0A（出厂） | **2.00W** | 1.30W | 3.0h |
| **0.6A（建议）** | 1.20W | 0.78W | **4.3h** |
| 0.5A | 1.00W | 0.65W | 5.0h |

TP4056 有热调节会自己降流保护，但代价是**外壳发烫 + 充电变慢且不可预测**。儿童玩具不该出现烫手的外壳。
**结论：把模块上那颗 Rprog 电阻换成 2kΩ → 600mA（0.30C）**，过夜充满绰绰有余。

#### ⚠ 2. 模块是 28 长不是 26，一字排开放不下了

板长 87，DevKit 63 + TP4056 占板 26 = **89 > 87**。

**解法：TP4056 钻到 DevKit 底下。**

| | z |
|---|---|
| 承载底板板面 | 5.6 |
| TP4056 贴板直焊，板 1.6 | 5.6 … 7.2 |
| Type-C 座顶（+3.2） | **10.4** |
| DevKit 板底（低背排母 5.0 + 排针隔片 2.5） | **13.1** |

**余 2.7mm** ✅ 横向 TP4056 宽 17 < DevKit 两排排母间距约 20.5 ✅ 也塞得下。
Type-C 座顶 10.4 落在前端面开口 5.5~10.5 内 ✅ 高度天然对上。

即 TP4056 从板前沿伸出 2mm（x −73…−45），其中 −69…−45 段藏在 DevKit 肚子底下。

#### ℹ 保护电路会有两套（电池自带 + 模块上）

电池 PCM 截止 2.75V，模块 DW01 截止 2.5V → **电池自己的先动作**，模块那套是后备。两套 MOSFET 串联多约 30mV 压降（0.6A 下），可忽略。
注意模块说明里那条：**首次接电池可能无输出，需插充电器激活保护电路** —— 两套串联时更要留意，装配调试时别误判为坏板。

### 🔴 DRV8833 模块：电气够用，但与网表/选型对不上三处

实际引脚（2 排 × 8）：

```
NC     | VM        网表要的信号:
AIN2   | NC          VM AIN1 AIN2 GND AO1 AO2  ✅ 都有
AIN1   | GND         nSLEEP -> 模块标 STBY     ✅ 有(网表已预判到会叫 STBY)
STBY   | AO1         nFAULT                    ❌ **模块根本没引出来**
BIN1   | AO2
BIN2   | BO2
NC     | BO1
GND    | GND
```

#### ① 封装完全不对：选型锁的是 1×10 单排，实物是 2×8 双排

选型锁定 U2 = `1*10-2.54圆孔排母`，而实物是**两排各 8 脚、排间距约 15.24mm**。
**封装必须整个换掉**，PCB 焊盘全变。这是第三个要改封装的器件（前两个：J3 麦克风 2.0→2.54、SW3 拨动开关 2.54→2.0）。

#### ② nFAULT 引不出来 → 网表 N12 作废

网表 `N12 = M_FAULT (U1.GPIO38, U2.nFAULT, R6.2)` 和上拉电阻 **R6 都要删掉**，GPIO38 释放为空闲。
（网表 §待核实清单里本来就写着"nFAULT 可能标 FLT ——需核实"，现在核实结果是：**没有这个脚**。）

影响：失去过温/过流/欠压的硬件故障通知。但网表 §4 早就写明「nFAULT 阈值 2~3.3A，远高于 N20 实际电流，**它救不了防砸**，只在真正电气故障时起作用」——所以损失有限，防砸本来就走行程超时。

#### ③ ✅ 高度没问题，可以插排母

用户确认**模块整体高度约 5mm，没有高电容**（我先前把照片上那个金色件误判成 6mm 的立式电解电容）。

| | 叠高 | 净空 | |
|---|---|---|---|
| 低背 5.0 排母 + 隔片 2.5 + 模块 5.0 | **12.5** | 13.4（`BASE_H`=22）| ✅ 余 0.9 |
| 同上 | 12.5 | 14.4（`BASE_H`=23）| ✅ 余 1.9 |

**之前"只能直焊、不可插拔"的担心解除。**

#### ④ 占位很紧

18.1 × 21.1 = 382mm²，建议分区的"上带"是 63 × 21.5 = 1354mm²，占 28%。
注意 **21.1 vs 上带宽 21.5，只余 0.4mm**，几乎贴满——PCB 布局时它基本吃掉整个带宽。

#### ℹ 两条不用担心的

- 卖家写「STBY 接 5V 工作」，但 DRV8833 手册的 V_IH 最小 1.5V，**3.3V GPIO 直接驱动没问题**，不需要电平转换。
- 引脚说明里提到的 `PWMA/PWMB` 是从 TB6612 描述抄来的，实际引脚表里没有。**DRV8833 的 PWM 直接加在 AIN1/AIN2 上**，与我们的设计一致（GPIO9/10 走 LEDC 20kHz）。

### ✅ 改选 MT3608 —— 高度 7mm 是决定性的

SX1308 高 **12mm**，DevKit 肚子只有 7.5mm，只能摊在明面上；MT3608 高 **7mm**，**能藏进肚子**。占位虽然更大（**37×17** vs 23×16.3），但藏起来就等于不占板面积，净收益远大于损失。

| | SX1308 | **MT3608** |
|---|---|---|
| 高度 | 12 ❌ 藏不进 | **7** ✅ 藏得进 |
| 外形 | 23 × 16.3 | **37 × 17** 📄（已定案）|
| 输入 | 2~24V | 2~15V（电池 3~4.2V 仍 ✅）|
| 输出 | 2~28V | >5~28V |
| 效率 | 95% | >93% |

~~**⚠ 外形要二选一**：详情页文字写 36×17×7，而实物照片标 30.0×17.0~~

**✅ 2026-08-13 已定案：实物尺寸图标注 37.0 × 17.0，重 4.39g**，颜色分类选的就是"MT3608升压板"（无 USB 座）。
所以**三个数都不对**——详情页文字的 36 少 1mm，之前记的 30.0 是看错了另一张图。**以 37 × 17 为准**，封装丝印按此画。

**⚠ 输出下限**：MT3608 标 ">5V~28V"，我们要 **5.1~5.2V**，正好压在范围最低端，调压时电位器要转到接近底部。

**⚠ 调压两条实操提醒**（详情页明写）：
1. **电位器面对胸口，逆时针转升压**
2. **若发现输出总等于输入、调不动，先逆时针旋转电位器 10 圈以上**再调 —— 这是多圈电位器没转到工作区，不是坏板

### ✅ 两个模块都能藏进 DevKit 肚子

肚子 63.6 长 × 25.4 宽（排针之间约 22.9 可用）：

| | 长度占用 |
|---|---|
| TP4056 —— Type-C 和指示灯那端必须伸出板前沿，只有约 **20mm** 在 DevKit 下 | 20 |
| MT3608 | 36 |
| 合计 | **56 < 63.6** ✅ |

**净空校核**：

| U1 排母 | `BASE_H` | 肚子净空 | TP4056(4.8) | MT3608(7.0) |
|---|---|---|---|---|
| 5.0mm | 22 | 7.5 | 余 2.7 ✅ | **余 0.5** ⚠ 太紧 |
| **7.0mm** | **23** | **9.5** | 余 4.7 ✅ | **余 2.5** ✅ |

**建议改用 7.0mm 排母 + `BASE_H` 23。** 0.5mm 余量扛不住打印公差和 DevKit 底面可能有的贴片件。

> `BASE_H` 23 超过了此前算的上限 22.5 —— 但那个上限来自 `switch_plate` 是整块方板（底面 = `PIV_Z − SW_HOLE_R − 5` 会低于闸体地板）。**托板本来就要改成两块独立安装台**，改完这个限制自动消失（新约束只要 `PIV_Z ≥ 12`，即 `BASE_H ≤ 30`）。

### ✅ 已定：方案 A + 底座各向再放宽 5mm

用户拍板：**方案 A（不藏升压、放大板子）**，并且**各方向再多留 5mm 余量，高度放宽到 25mm**。

| | 当时定的 | **2026-08-14 现值** |
|---|---|---|
| **底座** | ~~163 × 63 × 25~~ | **183 × 73 × 25** |
| **承载底板** | ~~100 × 55~~ | **120 × 65** |
| `TRAY_H` | 22 | 22（不变）|
| 板面以上净空 | **16.4mm** | 16.4mm（不变，高度没改）|
| `PIV_Z` = 42 − 25 | **17** | 17（不变）|
| 闸体顶面离地 | 25 + 62 = 87 | 87（不变）|

> 🔴 **板子后来又放大了一次**：U4 实测 37mm 长（当时按 SX1308 的 23mm 估的），100×55 放不下 → **120 × 65**，底座随 `BASE_L=板长+63`、`BASE_W=板宽+8` 变成 **183 × 73 × 25**。**高度方向未变**，所以上面的净空/`PIV_Z`/闸体高度全部照旧。详见 [机械约束 §七之二](道闸玩具_底板机械约束_v1.md)。

净空一下子宽裕了，之前所有卡脖子的地方全部解除：

| | 叠高 | 余量 |
|---|---|---|
| U1 DevKit（**5.0 低背排母**）| 12.17 | **4.23mm** ✅ |
| U2 DRV8833（5.0 排母）| 12.5 | **3.90mm** ✅ |
| U4 MT3608（摊明面直焊）| 7.0 | **9.40mm** ✅ |
| SW1/SW2 + 按键帽 | — | 按新 `TRAY_H` 重算 |

板面积：除 DevKit 外剩 3723mm²，需放 1714mm² → **占用率 46%** ✅ 很宽松。

`PIV_Z`=17 对闸体内部的校核：凸轮底 z=7.7、0° 位开关本体最低 z=10.7，都远高于闸体地板 2 ✅

<details><summary>（原 A/B 两方案对比，已选 A，保留备查）</summary>

### 升压模块藏不藏 —— 两条路，要选一条

MT3608 高 7mm，DevKit 用 5.0 排母时肚子只有 7.5mm，**只余 0.5mm**，扛不住公差。要么加高底座换 7.0 排母把肚子撑到 9.5，要么干脆不藏、把板子放大。

| | **方案 A：不藏，放大板子** | **方案 B：藏起来，加高底座** |
|---|---|---|
| 承载底板 | **95 × 50** | 87 × 47（不变） |
| 底座 | **158 × 58 × 22** | **150 × 55 × 24** |
| U1 排母 | 5.0（不变） | **7.0** |
| DevKit 叠高余量 | 12.17 / 13.4 → **1.23mm** ✅ | 14.17 / 15.4 → **1.23mm** ✅ |
| 除 DevKit 外板面占用率 | 58% ✅ | 48% ✅ |
| MT3608 | 摊在明面，**电位器随时可调** | 藏肚子里，**调电位器要先拔 DevKit** |
| 代价 | 底座长 8mm、宽 3mm | 底座高 4mm（比原始锁定值 20 高 4） |

> 方案 B 若只加到 `BASE_H`=23，DevKit 余量只剩 **0.23mm**，太紧；要加到 **24** 才有 1.23mm。所以 B 的真实代价是底座高 24。

**我倾向方案 A**，两个理由：
1. **可维护性** —— MT3608 的电位器要现场调到 5.1~5.2V，还可能需要复调。藏在 DevKit 底下每次都要拔插主控板，而 DevKit 是插排母的，反复插拔会松。
2. **符合你定的原则** —— "先以板子尺寸为主，结构件随板子调整"。加大板子是顺着这条原则走；靠加高底座去迁就一块 87×47 的板，是反过来的。

底座 158×58×22 对一根 300mm 的闸杆来说比例上更稳，也比 150×55×24 那个"又矮又厚"的比例好看。

**但这条你拍板。**

</details>

<details><summary>（原"板子不用放大"的结论，前提是 MT3608 藏肚子，保留备查）</summary>

### 板子不用放大了

两个模块藏起来后重算：

| 板子 | 除 DevKit 外剩余 | 还需放 | 占用率 |
|---|---|---|---|
| **87 × 47（现值）** | 2312 mm² | 1102 mm² | **48%** ✅ |
| 95 × 50 | 2973 | 1102 | 37% ✅ |

（"还需放"= DRV8833 382 + 端子 376 + 开关/蜂鸣器/电解电容 242 + TP4056 露出段 102）

**保持 87 × 47、底座保持 150 × 55 即可**，只有 `BASE_H` 从 22 加到 23。

（后续修正：`BASE_H`=23 时 DevKit 叠高余量只有 0.23mm，太紧，要 24 才够；于是演变成上面 A/B 两个方案。）

</details>

### ⚠ 指示灯：打底孔不行，但有更好的办法

你说"上面看不到就在下面打孔"——思路对，但 **TP4056 的指示灯长在模块正面朝上**，模块 PCB 会把光完全挡住，底下打孔看不见。

**更好的办法：让 TP4056 的指示灯那一端露在 DevKit 外面。**
指示灯就在 Type-C 那一端附近，而 Type-C 端本来就必须伸出板前沿对准前端面开口。只要 DevKit 的前边缘往后退到 x≈−65，TP4056 前端约 8mm（含两颗灯）就露在外面 ✅ 上盖正上方开孔即可，模块其余 20mm 照样藏在肚子里。

**孔位等 PCB 布局定了再给**（取决于灯在模块上的确切位置），结构件跟着走。

<details><summary>（原 SX1308 分析，已被 MT3608 取代，保留备查）</summary>

### SX1308 电气完全够用

| | 规格 | 我们的用法 | |
|---|---|---|---|
| 输入 | 2~24V | 电池 3.0~4.2V | ✅ |
| 输出 | 2~28V 可调 | 需 5.1~5.2V | ✅ 升压只能升不能降，4.2→5.2 是升压 ✅ |
| 电流 | ≤2A | 峰值 0.6A | ✅ |
| 输入电流（Vin=3.0V 最差） | — | 1.18A | ✅ SX1308 内部开关限流 4A |

</details>

### ✅ 升压模块封装已改：不是 1×4 排针，是 4 个角上的焊盘

选型锁定 U4 = `PM254V-11-04-H71-U（1×4 排母）`，而实物是 **4 个大焊盘分布在模块两端**（IN+/IN− 一端，OUT+/OUT− 另一端），根本不是一排。**封装已换成 2+2 布局。**

~~⚠ 焊盘间距图上没标，做封装前必须实测~~ → **2026-08-13 用户实测到手**：

| | 值 |
|---|---|
| **长边（36）方向 两孔中心距** | **30**（每端内缩 3）📏 |
| **短边（17）方向 两孔中心距** | **7**（每侧内缩 5）📏 |
| 孔径 / 焊盘 | φ1.651（=65mil） / 4×4 |
| 焊盘坐标 | (∓15, ±3.5) |

封装已建：个人库 `MODULE-TH_MT3608-37x17-4PAD`。**编号 1=IN+ 2=IN− 3=OUT+ 4=OUT−**。

**✅ 正极排布已确认**：实物图上 `VOUT+` 与 `VIN+` 同在一条长边，`VOUT−`/`VIN−` 在另一条边——即"+"走一边、"−"走另一边，与建封装时的取法一致，**不用改**。

### ⚠ 遗留：工程库里的封装副本可能还是 36mm 外框

EasyEDA 把封装**复制一份存进工程库**，改个人库的原件不会自动传导。外框从 36 改到 37 之后重新放置 U4，弹出了"发现这个器件有更新"的对话框，点「更新」后：

| | 结果 |
|---|---|
| 器件名 | ✅ 已刷新为 `MT3608升压模块-37x17-4焊盘` |
| 封装名 | ❌ 工程库副本仍叫 `...-36x17-4PAD` |
| 封装几何 | **未知**，工程库副本 `openInEditor` 打不开（`"project"`/`undefined` 都失败），API 无法查证 |

**影响极小**：两个版本的**焊盘完全相同**（30×7、φ1.651、4×4），差异只有丝印外框那 1mm。不影响装配、网表和可制造性，只影响 PCB 里的目视占位框。

**转 PCB 时验收**：封装落到 PCB 文档后可以直接读几何，那时确认外框是 37 还是 36；若仍是 36，在 PCB 库里改那 4 根丝印线即可。

### ⚠ 可调电位器是个风险点

输出靠 10K 蓝色电位器手调。两个隐患：

1. **调错或松动会烧板** —— 这个电位器能把输出推到 28V，直接灌进 ESP32 就报废。
2. **玩具会被摇晃**，微调电位器长期振动有漂移风险。

**处置**：调到 5.1~5.2V 后**必须点胶固定电位器**。小批量的话更稳妥的做法是量出分压比、换成两颗固定贴片电阻。
**装配顺序**：升压模块要在**插 DevKit 之前**调好并测量确认，因为它会被藏在 DevKit 底下（见下）。

### 🔴 板面积不够了 —— 按"板子尺寸为主"应放大板子

**新原则（用户定）**：*尺寸稍有不确定的多留空间；**先以板子尺寸为主，结构件随板子调整***。

模块靠排针架空，走线可以从模块 body 底下过，所以真正的约束是 **body 不能互相重叠**，不是"面积被吃掉"。按 body 占位重算：

| 器件 | 占位 mm² |
|---|---|
| U1 DevKit 63.6×25.4 | 1615 |
| U3 TP4056 28×17 | 476（**不能再藏 DevKit 底下**，方案 C 要看充电灯）|
| U2 DRV8833 18.1×21.1 | 382 |
| U4 SX1308 23×16.3 | 375（**高 12，也塞不进 DevKit 底下**）|
| J1/J2/J4 端子 + J3 | 376 |
| SW1/SW2/SW3/LS1/C1/C3 | 242 |
| **合计** | **3466** |

| 板子 | 面积 | body 占用率 | 对应底座 |
|---|---|---|---|
| **87 × 47（现）** | 4089 | **85%** ❌ 布不通 | 150 × 55 |
| 95 × 50 | 4750 | 73% ⚠ 仍紧 | 158 × 58 |
| **100 × 52** | 5200 | **67%** ✅ | **163 × 60** |
| 110 × 55 | 6050 | 57% ✅ 宽松 | 173 × 63 |

换算关系（固定不变）：
```
BASE_L = 板长 + 63     (电池仓 53 + 挡边 3 + 间隙 1 + 端部余量 2 + 前后壁 4)
BASE_W = 板宽 + 8      (两侧各 2 间隙 + 2 壁)
```

**建议板子做到 100 × 52，底座相应变成 163 × 60 × 22。** 长了 13mm、宽了 5mm，对一个 300mm 闸杆的道闸玩具来说比例上完全不突兀，反而更稳。

**但板子最终多大由你 PCB 布局说了算** —— 布完告诉我实际外形，我按上面两条换算式调结构。

<details><summary>（原"上带装不下"的分析，前提已变，保留备查）</summary>

| 器件 | 占位 |
|---|---|
| DRV8833 | 382 mm² |
| SX1308 | 375 mm² |
| 蜂鸣器 φ9 | 64 |
| SW1/SW2 | 72 |
| J1 KF128-2P | 80 |
| J2 KF128-3P | 120 |
| J3 6P | 75 |
| C1 + C3 | 51 |
| **合计** | **1219 mm²** |

建议分区的"上带"只有 63 × 21.5 = **1354 mm²**，占用率 **90%**。PCB 还要走线，占用率超过 60~70% 基本布不通。**上带装不下。**

**唯一的出路是用 DevKit 肚子底下那 1606 mm²**：

| 藏在底下的模块 | 高度 | 余量（DevKit 板底离承载板面 7.5mm） |
|---|---|---|
| TP4056（板 1.6 + Type-C 座 3.2） | 4.8 | **2.7mm** ✅ |
| SX1308（板 1.6 + 电位器约 5） | 6.6 | **0.9mm** ⚠ 很紧 |

两个模块都塞得进去，但 SX1308 只余 0.9mm，**电位器实际高度必须实测**——超过 5.9mm 就顶到 DevKit 了。

（后续实测：SX1308 高 **12mm**，DevKit 肚子只有 7.5mm，**根本塞不进**；TP4056 又因指示灯方案不能藏。两个模块都得摊在明面上，所以改为放大板子。）

</details>

### ✅ J3 不用改封装（更正此前的错误结论）

我此前写"INMP441 是 2.54mm 排针、插不上、必须改封装"，**两层都错了**：

1. **模块实际就是 2mm 间距**（卖家尺寸图明确标注），J3 原本的 2.0mm 封装本来就对；
2. 更根本的是——**麦克风固定在闸体上，靠飞线接到底板**，它根本不插在 J3 上。既然是飞线，模块的引脚间距和 J3 的间距**不需要一致**，J3 只要匹配我们用的插头即可。

错误根源：我脑补了"模块直接插 J3"这个前提，没考虑它在闸体里、隔着约 55mm 飞线。**J3 从待改封装清单中划掉。**

### ⚠ 麦克风固定结构还没做

模块是 **φ14 圆板、厚仅 1mm**，装在闸体前面板内侧、对准 4 个 φ1.8 格栅孔（z=38，离地 60）。CAD 里目前**只有格栅孔，没有任何支架**。

φ14×1mm 的圆板很好固定，建议做成**浅圆窝 + 两片压舌**：前面板内侧铣圆窝，上下各出一片小压舌把板压住。零螺丝、零胶。

> **CAD v3.0 实建：窝取 φ15.4（不是 φ14.6）× 深 1.2，压舌上 0.6 / 下 1.2。**
> 窝比板大 1.4mm 是**故意的** —— 两片压舌都是死的（不靠塑料弹性，1.5mm 厚的 PLA 舌头掰不动），
> 装配靠这 0.7mm 半径余隙：把板往下压到底，上边就能越过上压舌那 0.6mm 的覆盖量，
> 松手后板落回中间，上下都咬住。φ14.6 只有 0.3mm 余隙，这个动作做不出来。
> 声学上不需要对准哪个孔：板与窝底之间那 0.2mm 缝就是共用声腔，4 个格栅孔通到哪儿都行。

**接线**：焊飞线到 6 个焊盘（L/R 就近接 GND，实走 **5 根**），沿闸体内壁下到底板 φ8 走线孔，全长约 55mm。**I2S 时钟走这么长必须绞合**（SCK 与 GND 绞、SD 与 GND 绞）。

---

## 3. 电池

| 项 | 型号 | 标称 (mm) | 带保护板实际 | 仓位 (CAD) | 来源 |
|---|---|---|---|---|---|
| 主机电池 | 103450 LiPo **2000mAh**（BOM 原写 1800）| 产品尺寸 **50 × 34 × 10**；重 34g；保护齐全（过充/过放/过流/短路）；充 0.5C / 放 1C；0.5C 循环 500 周后 ≥80% | **含保护板和引线的成品尺寸 = 51 × 34 × 10**（卖家确认） | 仓改为 x **20**…73（**53**），y ±18（36），z 2…12 | 📄 全部确定 |
| 遥控器电池 | 502030 LiPo 250mAh 🔒 | 电芯主体 5 × 20 × 30 | 🔴 **实测成品 32 × 20 × 4.6**（2026-08-15 用户量的，含保护板与引线）| 仓做 **33.5 × 21.5 × 5.5** | 📏 **实测** |

> ⚠ **比原先估的薄 2.4mm**：早先按"含保护板 +1~2mm"估成 7×21×32，实际只有 4.6 厚。
> 遥控器外壳因此从 27.5 直接降到 **26**（高度链见[遥控器网表基准 §6c](道闸玩具_遥控器网表基准_v1.md)）。
> 教训还是那条：**估的尺寸和实测差 2.4mm，足以改变整个结构方案**。

### ✅ 电池尺寸已闭合：成品 51 × 34 × 10，仓加长 1mm 即可

卖家确认**含保护板和引线的成品尺寸 = 51 × 34 × 10**（裸电芯 50，PCM 只多 1mm）。这是最好的结果——**不用重排电池仓，也不用动承载底板**。

| 仓长 | 每边余量 | −X 挡边 | 与底板(x=16)间隙 |
|---|---|---|---|
| 52（现值） | 0.5mm | x=18…21 | 2mm |
| **53** | **1.0mm** | **x=17…20** | **1mm** ✅ |
| 54 | 1.5mm | x=16…19 | 0（顶到底板） |

软包电芯在打印件仓里的常规放量是**每边 1mm**，所以取仓长 **53**：只把 `BAT_X0` 从 21 改成 **20**，挡边随之到 x=17…20，与底板留 1mm。**承载底板长度不用动。**

- 宽度：仓 36 vs 电芯 34 → 每边 1.0mm ✅
- 厚度：围挡 10 高是**侧向限位**，上方到上盖背面（z=19）还有 7mm 让循环鼓胀 ✅
- 引线：从挡边上方（z 12…19 的 7mm 空隙）跨过去接 J4，不占长度 ✅
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

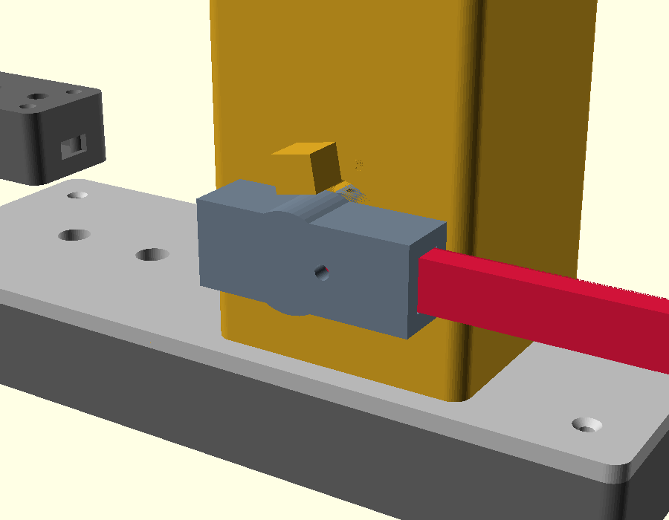
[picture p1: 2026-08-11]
cad/png/hub_bar.png

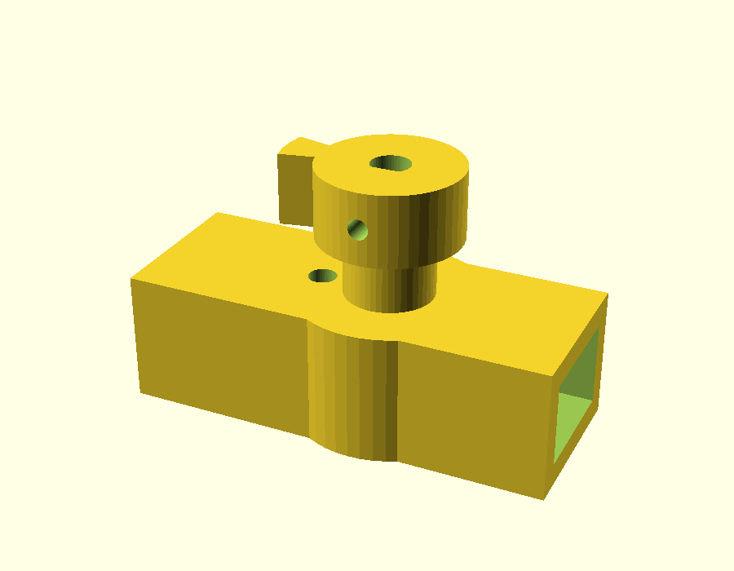
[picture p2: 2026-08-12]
cad/png/hub_motor.png

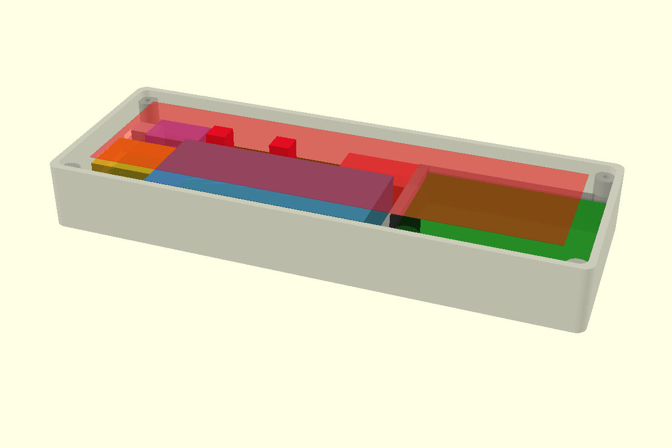
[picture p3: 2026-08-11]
cad/png/layout_v25.png

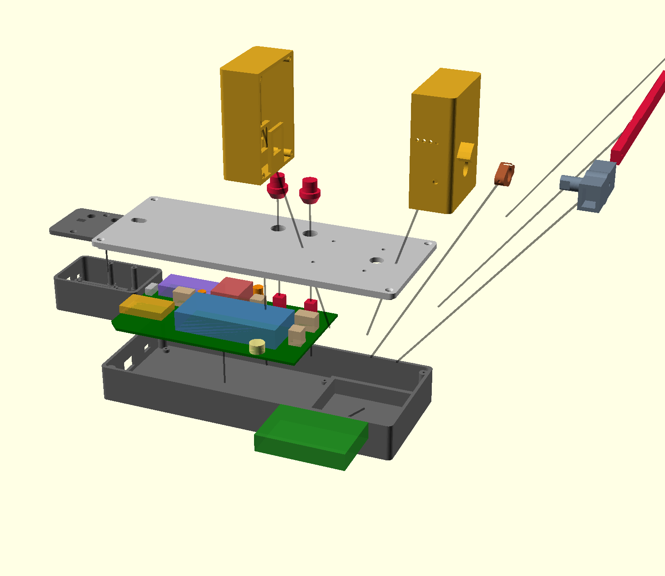
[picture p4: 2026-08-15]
cad/png/explode.png

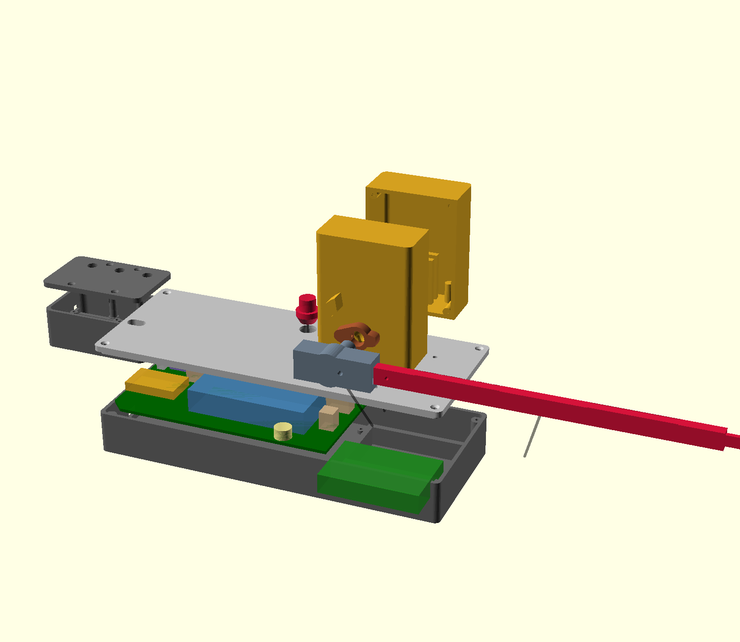
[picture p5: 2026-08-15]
cad/png/explode_half.png

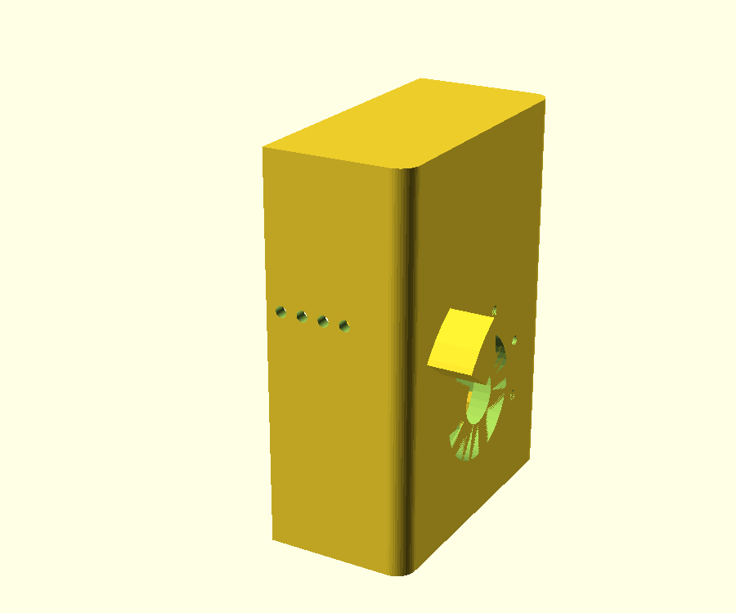
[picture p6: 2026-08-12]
cad/png/house_l_stop.png

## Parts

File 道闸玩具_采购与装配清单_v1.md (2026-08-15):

# 道闸玩具 · 采购与装配清单 v1

> 面向**第一次做硬件**的人写的。看完这份你应该能：知道买什么、哪些嘉立创帮你焊、哪些自己焊、按什么顺序装。
> 尺寸依据：[元器件尺寸基准](道闸玩具_元器件尺寸基准_v1.md)。电路依据：[网表基准 v2](道闸玩具_底板网表基准_v2.md)。

---

## 0. 先搞懂三个概念

做这个东西，零件分三类，**处理方式完全不同**：

| 类别 | 是什么 | 谁来焊 |
| --- | --- | --- |
| **A 类 · 贴片件（SMD）** | 米粒大小、贴在板面上的电阻电容三极管 | 🔴 **本次自己手焊**（见下） |
| **B 类 · 直插件（THT）** | 有脚要插进孔里的：端子、开关、电解电容、排母 | **你自己焊** |
| **C 类 · 模块和机械件**  | 成品小板、电机、电池、螺丝、3D 打印件 | **你自己插/装**，基本不用焊 |

> 🔴 **2026-08-15 改口：本次打板不走 SMT 贴片，A 类也自己手焊。** 原文写的"嘉立创打板时一起贴，你收到就是焊好的"作废，下单时**只买裸板、不勾贴片服务**。
>
> 两块板一共只有 **9 颗**贴片件，付贴片费不划算：
>
> | 板 | 位号 | 值 | 封装 |
> |---|---|---|---|
> | 主机 | C2 / C4 / C5 | 100nF 50V X7R | 0603 |
> | 主机 | R3 / R4 | 100kΩ ±1% | 0603 |
> | 主机 | R5 | 1kΩ ±1% | 0603 |
> | 主机 | D1 | 1N5819 | SMA（有极性）|
> | 主机 | Q1 | S8050 NPN | SOT-23-3（有方向）|
> | 遥控 | C1 | 10µF | 0805 |
>
> **采购上要跟着变的两件事**：① 这 9 种料自己按 LCSC 编号买（编号见 [选型锁定](道闸玩具_底板选型锁定_v1.md)）；② **0603 每种至少备 10 颗**，手焊会飞会烧会掉。
>
> **装配顺序也跟着变**：贴片件必须在**所有直插件之前**焊完——排母和电解电容一上板，0603 就彻底够不着了。手法、立碑防范、极性识别见[装配手册](道闸玩具_装配手册_v1.html)第 1 步。

---

## 1. A 类 · 打板时让嘉立创贴（你不用管）

下单时勾选 **SMT 贴片**，把下面这些填进 BOM 表。全是最常见的通用料，嘉立创基本料库都有。

| 位号 | 器件 | 封装 | 数量 | 说明 |
| --- | --- | --- | ---- | --- |
| C2, C4, C5 | 100nF 50V X7R | **0603** | 3 | 去耦 |
| R3, R4 | 100kΩ ±1% | **0603** | 2 | 电池电压采样分压 |
| R5 | 1kΩ ±1% | **0603** | 1 | 蜂鸣器三极管基极限流 |
| D1 | 1N5819 肖特基 | **SMA** | 1 | 电源隔离 |
| Q1 | S8050 NPN | **SOT-23-3** | 1 | 驱动蜂鸣器 |

**共 5 种、8 颗。** 成本几块钱，但省掉了最难焊的部分——0603 只有 1.6×0.8mm，新手手焊很痛苦。

> ⚠️ **R6（10kΩ）已从设计中删除**，不要买、不要贴。原本是给 DRV8833 的 `nFAULT` 做上拉的，但实际买的模块没引出这个脚。

---

## 2. B 类 · 你自己焊在板上（直插件）

这些都是大脚件，**用普通烙铁 + 松香焊锡就能焊**，是新手最好的练手对象。

| 位号 | 器件 | 数量 | 采购要点 |
| --- | --- | ---- | --- |
| C1 | 470µF/10V 电解电容 | 1 | φ6.3、脚距 2.5 |
| C3 | 220µF/10V 电解电容 | 1 | φ5、脚距 2.0 |
| SW1, SW2 | 轻触开关**6×6×12** | 2 | **必须 12mm 高**；**动作力选 100~160gf**，别买 300gf（小孩按不动） |
| SW3 | 拨动开关**SK12D07VG7** | 1 | **两档、卧式侧拨**；脚距 **2.0mm**（不是 2.54） |
| LS1 | 有源蜂鸣器 3V | 1 | φ9 × 高 5.5，脚距 5.0 |
| J1, J4 | KF128-3.81**2P** 接线端子 | 2 | 电机、电池 |
| J2 | KF128-3.81**3P** 接线端子 | 1 | 两个限位开关 |
| J3 | 6P 排针或排母 | 1 | 接麦克风飞线，2.54 或 2.0 都行 |
| — | **2.54 低背排母 5.0mm 高 1×22** | 2 | **给 U1 DevKit 用** |
| — | **2.54 低背排母 5.0mm 高 1×8**  | 2 | **给 U2 DRV8833 用** |

### ⚠️ 排母必须买"低背 5.0mm"，这是全项目最容易踩的坑

市面上默认卖的排母是 **8.5mm 高**。用 8.5 的话，DevKit 插上去总高会超出底座内腔，**盖子盖不上**。

买的时候搜 **"2.54 低背排母 5.0"** 或 **"短体排母 H=5.0"**，认准**本体高度 5.0mm**。

> 为什么差这么多：DevKit 插上去是**四层叠高** = 排母 5.0 + DevKit 自带排针的塑料隔片 2.5 + DevKit 板 1.57 + 芯片模组 3.1 = **12.17mm**。用 8.5 的排母就是 15.67mm，超了。

---

## 3. C 类 · 模块与机械件（自己插、自己装）

### 3.1 电子模块

| 位号 | 型号 | 数量 | 采购要点 |
| ---- | --- | ---- | --- |
| U1 | **ESP32-S3-DevKitC-1 N16R8**【向下焊】 | 1 | **必须 N16R8**（16MB Flash）。N8R8 装不下语音识别模型 |
| U2 | **DRV8833 驱动板**（红板，排针已焊好） | 1 | 2 排 × 8 脚 |
| U3 | **TP4056 Type-C 充电板（带保护）** | 1 | **必须带保护**：认准板上有 **B+/B− 和 OUT+/OUT− 四个端子** |
| U4 | **MT3608 升压板** | 1 | **37×17 那款**（无 USB 座、颜色分类写"MT3608升压板"），不是带 Micro USB 座的版本。四角 4 个大焊盘，**孔距 30×7** |
| — | **INMP441 麦克风模块**（不焊排针版） | 1 | φ14 圆板 |

### 3.2 机械与电源

| 器件 | 数量 | 采购要点 |
| --- | ---- | --- |
| **N20 减速电机 6V 15rpm** | 1 | D 形轴 φ3、伸出 10mm；机身 10×12×25.2 |
| **限位微动开关 ZIPPY DF-P1S-1E-M-Z** | 2 | **必须带簧片杠杆**（直杆 13mm）、**焊线脚**。无杠杆的直动式会被凸轮压毁 |
| **103450 锂电池 2000mAh 带保护板** | 1 | 成品 51×34×10 |
| **M5 六角螺母（碳钢）** | 1~2  | 转毂配重，别买不锈钢（密度低） |

> 遥控器的件全部单列在下面 §3.5，别在这张表里找。

### 3.5 遥控器 BOM（2026-08-15 定稿，独立于主机）

遥控器是**单独一块板 + 单独的壳**，采购时当成第二个小项目。

| 位号 | 器件 | 数量 | 采购要点 |
|---|---|---|---|
| U1 | **ESP32-C3 SuperMini** | 1 | 22.52 × 18。**买焊针向下的版本** |
| — | **2.54 低背排母 5.0mm 1×8** | **2** | 🔴 **给 U1 用，必须低背 5.0**（和主机同款，别买 8.5）。模块要反复拔下来改程序，**不能直焊** |
| U2 | **TP4056 Type-C 充电板（带保护）** | 1 | 28 × 17。**必须带保护**：认准 B+/B− 和 OUT+/OUT− 四个端子 |
| SW1~SW3 | **6×6×9 轻触开关** | 3 | ⚠ 高度是 **9mm**，不是主机那种 12mm。动作力选 **100~160gf** |
| SW4 | **SK12D07VG7 拨动开关** | 1 | 🔴 **不是 SS12D00** —— 那是立式拨柄朝上，而开口在端面，方向对不上（主机踩过一次） |
| C1 | 10µF/25V **0805 陶瓷** | 1 | LCSC C15850。⚠ **不能用电解电容**，φ5×11 装不下 |
| — | **502030 锂电池 250mAh 带保护板** | 1 | **实测成品 32 × 20 × 4.6**（含保护板引线）|
| — | 电池引线焊盘 | — | 板上是 1×2 的 2.54 通孔，**不装排针**，引线直接焊进去。不能用 KF128 端子（高 9.5mm 装不下）|
| — | **M2×8 十字沉头自攻** | 4 | 遥控器上下壳锁紧 |

**3D 打印件**：`rc_bottom` / `rc_top` 各 1、`rc_btn_cap` **×2**（树脂）。

> 🔴 **上盖只开两个按键孔：抬杆 (−16,9) 和落杆 (2,9)。** 三个按钮对 6~10 岁的孩子容易误操作，用户拍板砍掉复位那颗的孔。
> **SW3 复位开关仍焊在板上、不拆，PCB 一点没动** —— 只是上盖那块变成实心面板，手指按不到。复位功能不丢：主机的离线语音本来就有「复位」这条命令。

**遥控器不需要的东西**（早期方案里有，已全部取消）：

- ❌ 状态灯（WS2812 / 板载 LED 都不用，上盖不开灯孔）
- ❌ 电量检测（100k/100k 分压静态就吃 18.5µA，而深睡指标 <20µA）
- ❌ 任何电阻 —— **整块板一颗电阻都没有**
- ❌ U1 的烧录口不开在外壳上（充电器插错会经 5V 脚倒灌进电池；改成拆壳拔模块烧录）

### 3.3 螺丝

详见 [紧固件清单](道闸玩具_紧固件清单_v1.md)。**全部是 M2 自攻螺丝**（塑件专用，不是机牙）。

懒人方案：买一盒 **M2 十字沉头自攻套装**（含 6/8/10/12mm）+ 一盒 **M2 十字盘头自攻套装**，再单买 **4 颗 M2×30 沉头**，全部齐活，约 20 元。

### 3.4 辅料

| 物品 | 用途 |
| --- | --- |
| 电烙铁（60W 可调温）+ 焊锡丝 + 松香 | 焊 B 类件和飞线 |
| 细导线（26~28AWG，多股软线） | 麦克风、限位开关、电机、电池的飞线 |
| 热缩管 | 飞线接头绝缘 |
| 502 胶 / 热熔胶 | 固定配重螺母、升压电位器、走线 |
| EVA 泡棉 | 压住电池防窜动 |
| 万用表 | **必备**，调升压输出电压要用 |

---

## 4. 3D 打印件清单

| 文件 | 零件 | 材料建议 | 数量 |
| --- | --- | --- | ---- |
| `base_tray` | 底座下托盘 | PLA | 1 |
| `base_top` | 底座上盖 | PLA | 1 |
| `house_l` / `house_r`  | 闸体左右壳 | PLA | 各 1 |
| `hub` | 转毂主体（臂 + 轴 + 电机孔） | **树脂或 PETG，100% 填充** | 1 |
| `cam` | 凸轮盘 | **树脂或 PETG** | 1 |
| `btn_cap` | 按键帽 | **树脂**（间隙要 0.3mm） | 2 |
| `bar_a` / `bar_b` | 闸杆两段 | PLA | 各 1 |
| `rc_bottom` / `rc_top` | 遥控器上下壳（63×40×26） | PLA | 各 1 |
| `rc_btn_cap` | **遥控器按键帽（新增）** | **树脂** | **2**（只有抬杆/落杆开孔）|

> `hub`、`cam`、`btn_cap`、`rc_btn_cap` 建议树脂打印：转毂是唯一受力件，按键帽需要 0.3mm 的滑动配合精度，FDM 打不出来。

---

## 5. 装配流程（按顺序做，别跳）

### 阶段一 · 焊板子

1. **收到嘉立创的板**（A 类已贴好），先目视检查有无连锡
2. 焊 **B 类直插件**。顺序：**先矮后高** —— 电阻电容 → 排母 → 端子 → 开关 → 蜂鸣器
   - 排母焊之前先把 DevKit 插上去比一下，保证两排平行、不歪
3. 焊 **U3 TP4056** 和 **U4 MT3608**（贴板直焊，不用排母）
   - ⚠️ TP4056 的 Type-C 那一端朝 −X，**本体前沿与板边基本齐平**（封装决定，只能悬出 0.23mm，不是早期文档写的 2mm）
   - 🔴 **焊之前先拿要用的充电线试插一下**：外壁面到座口有 3.27mm 死区，靠**插头塑料头**穿过去。外壳开口已按实测塑料头 **11 × 6.5** 放大到 **12.5 × 8.0**（原来 10×5 是照金属壳开的，塑料头顶在外壁上只能插一半）。**换更粗的线就要重新量、重新放开口。**
4. **先别插 DevKit**

### 阶段二 · 调升压（**必须在插 DevKit 之前做**）

5. 电池接上 J4，拨动开关打开
6. 万用表量 **MT3608 的 OUT+ / OUT−**
7. **电位器面对自己，逆时针转升压**。若发现输出总等于输入调不动，**先逆时针连转 10 圈以上**再调
8. 调到 **5.1~5.2V**，然后**滴一滴胶固定电位器**
9. ⚠️ **这步做错会烧掉 ESP32**——升压最高能输出 28V。**没量准之前绝对不要插 DevKit**

### 阶段三 · 装闸体

10. **转毂主体**从闸体左壳**外侧**插入，轴颈穿过 φ8.5 壁孔和内侧的 φ12 轴承凸台进入腔内
11. **凸轮盘**从腔内套上轴颈。**相位不用对** —— 凸轮的 D 形孔和轴颈上的键面配合，只有一个方向能套进去，套进去就是对的
12. **拧凸轮顶丝**：把闸杆放到**落杆位（水平，0°）**，顶丝就正对闸体前面板上那个 **φ3 小孔**，长柄小螺丝刀从孔外捅进去拧
    - ⚠️ **这颗顶丝是转毂唯一的轴向固定**（拧紧后：往外拔 → 凸轮撞轴承凸台；往里推 → 夹杆臂撞外壁）。**务必拧紧，建议点一滴螺纹胶**
13. **N20 电机**沿 −Y 推进矩形隧道，D 形轴插进转毂的 D 孔，**注意 D 面对齐**（电机轴可以用手转到对上）
14. 装**两只限位开关**：M2 螺丝穿过开关本体的 φ2.2 孔，拧进**安装台上的径向长圆孔**
    - 两块安装台，一块朝 +X（落杆位那只）、一块朝 +Z（起杆位那只），互成 90°
    - ⚠️ **先别拧死**。手动转动转毂，调整开关径向位置到"凸起刚好压下、基圆刚好释放"，再拧紧。长圆孔给了 ±1.5mm
    - ⚠️ 自攻螺丝在长圆孔里只咬两条长边，**别使劲拧**，感觉到阻力就停
15. 焊限位开关飞线 → 引到 J2。⚠️ **J2 的两个限位端子是对调过的：第 2 脚 = 落杆限位，第 3 脚 = 起杆限位**
16. **合右壳**，4 颗 M2×30 沉头从右壳外侧拧进左壳。**细长螺丝务必扶正，别用电动批**

### 阶段四 · 装麦克风

17. INMP441 焊 **5 根飞线**（SCK / WS / SD / VDD / GND，L/R 就近接 GND）
18. **SCK 与 GND 绞合、SD 与 GND 绞合**——线长 55mm 以上，不绞会引入噪声
19. 圆板压进闸体前面板内侧的 **φ15.4 圆窝**：**先把板往下压到底**，让上边越过上压舌（上压舌只盖 0.6mm），再松手让板落回中间——上下两片压舌同时咬住
    - 窝比板大 1.4mm 是故意的，就是给这个动作留的余隙。板沉进去 1.2mm、比内壁面还低 0.2mm，不会被右壳挤到
    - 不用对准某个孔：板和窝底之间那 0.2mm 缝就是共用声腔，4 个格栅孔通到哪儿都行
20. 飞线沿内壁下到闸体底板 φ8 走线孔

### 阶段五 · 合底座

21. **按键帽 ×2** 从上盖背面放进沉孔（法兰 φ12 比通孔 φ9 大，**盖上以后就塞不进了**）
22. 闸体 → 上盖：从盖板背面往上拧 4 颗 M2 沉头。**必须在盖板扣到托盘之前拧**，否则伸不进螺丝刀
23. 承载底板落到 4 根支撑柱上，4 颗 M2×5 拧死
24. 电池塞进 +X 电池仓，**引线朝 −X**（朝底板那侧），垫 EVA 泡棉
25. 插上 **DevKit**（此时升压已确认 5.1~5.2V）
26. 走线：电机 → J1，电池 → J4，限位 → J2，麦克风 → J3
    - ⚠️ 闸体的走线孔在**电池正上方**（55, −16.5）。四组飞线下来后贴着电池顶面往 −X 走到板上（电池顶到上盖背面有 10mm 空隙），和电池自己的引线同一条通道
27. 合上盖，4 颗 M2×12 沉头。合之前确认按键帽能上下活动、不卡

### 阶段六 · 装闸杆

28. **配重**：1~2 颗 M5 螺母从转毂 −X 端滑进配重仓，点胶固定
29. 闸杆根段插进转毂插槽——**窄面朝下、8mm 那边立起来**，1 颗 M2×10 横穿
30. 末段套上插榫，1 颗 M2×6

---

## 6. 新手最容易踩的 6 个坑

1. **排母买成 8.5mm 高的** → 盖子盖不上。必须买**低背 5.0**。
2. **升压没调就插 DevKit** → 28V 灌进去，主控直接报废。**先调、先量、再插**。
3. **限位开关买成无杠杆的** → 凸轮升程 3.3mm，直动式行程只有 0.3mm，**会被压毁**。
4. **轻触开关买 300gf 的** → 6 岁小孩按不动。要 **100~160gf**。
5. **按键帽忘了先放** → 上盖扣上后法兰塞不进去，得全拆。
6. **TP4056 首次接电池没输出** → 这是保护电路没激活，**插上充电器充一下就好**，不是坏板。
7. **凸轮顶丝没拧紧** → 它是转毂**唯一的轴向固定**。松了闸杆一拉就把转毂拔出来。点螺纹胶。

---

## 7. 变更记录

| 版本 | 日期 | 说明 |
| ---- | --- | --- |
| v1.1 | 2026-08-14 | CAD 解冻到 v3.0 后回写装配细节：凸轮改为**键面定角度 + 前面板 φ3 孔拧顶丝**（不再"对相位"）；限位开关改拧**径向长圆孔**；麦克风圆窝的插入手法；走线孔挪到电池上方；TP4056 悬出量更正为 0.23mm |
| v1 | 2026-08-13 | 首版 |

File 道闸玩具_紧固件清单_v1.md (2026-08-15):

# 道闸玩具 · 紧固件采购清单 v1

对应 CAD 版本：`cad/daozha.scad` **v3.3**（2026-08-15，`BASE_H = 25`）
所有孔位、孔径、长度均由 v3.3 源码推算，v3.0 及更早版本不适用。

> **v3.0 → v3.3：规格和数量仍是 27 颗一颗没变，但有 4 处位置变了**（详见各节）：
> ① 闸体绕 Z **转了 90°**、`HS_X_ABS` 55 → **51.5**，固定点变成 **(36.5,±15) (66.5,±15)**；
> ② 承载底板 −X 两角是 **45°×7 倒角**，不是方缺口（原文写的 5×5 方缺口是错的，CAD 曾按方缺口建模，与 EDA 实际板框不符）；
> ③ 遥控器上盖螺柱位置**全变**（原 (±23,±9) 作废），且上盖**没有止口环**，过孔只穿 3mm；
> ④ 转毂配重端削短 3mm，配重仓跟着前移。

> ⚠️ 表中凡是依赖**元件**尺寸的长度（微动开关本体厚度、顶丝深度等）随 [元器件尺寸基准 v1](道闸玩具_元器件尺寸基准_v1.md) 的实测结果变动。

> **v2.6 → v3.0：规格和数量一颗没变（仍是 27 颗），但有 4 处位置/深度变了**：
> ① 角螺柱 (±70.5,±23) → **(±87,±32)**；② 闸体固定点 (25±15,±15) → **(55±15,±15)**；
> ③ 微动开关孔距 9.5 → **6.5**、半径 12.5 → **14.6**，且改成**径向长圆孔 + 4.5mm 盲底孔**（不再打穿外壁）；
> ④ 顶丝从"转毂上顶电机轴"改成"**凸轮上顶轴颈键面**"，长度 M2×6 → **M2×8**。
> 已经买了的不用重买，按新位置装即可。

---

## 一、一句话采购版

懒人方案：直接买一盒 **M2 十字沉头自攻螺丝套装**（含 6/8/10/12mm）+ 一盒 **M2 十字盘头自攻螺丝套装**（含 6/8/10mm），再单买 **4 颗 M2×30 沉头自攻** 和 **2 颗 M5 六角螺母**，全部齐活，成本约 20 元。

单买请按下表。**全部是自攻螺丝（塑件专用，PT / PA / KA 型），不是机牙螺丝**——塑件里没有预埋螺母，机牙螺丝拧不进去。

| 规格 | 数量 | 建议采购量 | 用途 |
|---|---|---|---|
| M2×12 十字**沉头**自攻 | 8 | 20 | 底座上盖×4、遥控器上盖×4 |
| M2×10 十字**沉头**自攻 | 4 | 10 | 闸体固定×4 |
| M2×30 十字**沉头**自攻 | 4 | 10 | 闸体左右壳对拧 |
| M2×10 十字**盘头**自攻 | 5 | 10 | 微动开关×4、转毂夹闸杆×1 |
| M2×6 十字**盘头**自攻 | 1 | 10 | 闸杆 A/B 对接 |
| M2×8 十字**盘头**自攻 | 1 | 10 | **凸轮顶丝**（顶在轴颈键面上）|
| M2×5 十字**盘头**自攻 | 4 | 10 | 承载底板固定 |
| M5 六角螺母（钢，非不锈钢） | 2 | 4 | 转毂配重，越重越好 |

**合计螺丝 27 颗**。建议每种多买一倍——自攻螺丝在 3D 打印件里返工两三次就会滑牙。

---

## 二、逐处明细

> 长度计量约定：**沉头螺丝的标称长度含头**（拧平后头顶与表面齐平）；**盘头螺丝的标称长度不含头**。下表已按此换算。

### 1. 底座上盖板 ↔ 底座下托盘

| 项 | 值 |
|---|---|
| 规格 | **M2×12 十字沉头自攻** |
| 数量 | 4 |
| 位置 | `BASE_BOSS` = **(±87, ±32)**，底座四角（在止口环正下方，并让开电池；**PCB 的 −X 两角是 45°×7 倒角**避它，净距 0.89mm）|
| 上盖过孔 | φ2.4 通孔，**贯穿 3mm 面板 + 2mm 背面止口 = 5mm** |
| 沉窝 | φ4.4 × 90°，在盖板正面 |
| 托盘螺柱 | 外径 φ6（嵌进内壁），底孔 φ1.7，顶面 z=**19.8**，可用螺纹深度 18.3mm |
| 螺纹啮合 | 7mm |
| 可替代 | M2×10（啮合 5mm，够用） |

### 2. 底座上盖板 ↔ 闸体

| 项 | 值 |
|---|---|
| 规格 | **M2×10 十字沉头自攻** |
| 数量 | 4 |
| 位置 | `HS_BOSS` = **(51.5±15, ±15)** = **(36.5,±15)(66.5,±15)**，闸体底部四角 |
| 方向 | **从盖板背面往上拧**，闸体外表面看不到螺丝 |
| 上盖过孔 | φ2.4 通孔 **3mm**，沉窝开在面板背面（z = 0） |
| 闸体螺柱 | 外径 φ4.4，高 12mm，底孔 φ1.7 深 11mm（自底面开口） |
| 螺纹啮合 | 7mm |

> v2.4 起这 4 点落在**止口环以内**，背面就是 3mm 面板，不再叠 2mm 止口，所以由 M2×12 改 M2×10。用 M2×12 会多顶进螺柱 2mm，不致命但没必要。
> 沉头拧平后与盖板背面齐平，**不会伸进腔内**，承载底板可以直接从下面经过。

> 装配顺序注意：这 4 颗必须在盖板扣到托盘**之前**拧好，否则伸不进螺丝刀。

> 🔴 **v3.3：闸体绕 Z 转了 90°，闸杆改沿 +Y 伸出**（原来沿 +X，整机在 X 上拉到 483mm，而且不像道闸——真道闸是机箱蹲在路边、杆子横跨路面）。
> **这 4 个孔位不用改**：`HS_BOSS` 是 (±15,±15) 的正方形阵列，90° 旋转正好映射到自身。变的只有 `HS_X_ABS` 55 → 51.5（由「夹杆臂外沿离底座 +X 边留 5mm」反推）。
> ⚠ **装的时候要认朝向**：转轴那一端靠近底座**无充电口**那侧（+X）。装反了充电口会被闸体挡住。

### 3. 闸体左壳 ↔ 右壳（对拧）

| 项 | 值 |
|---|---|
| 规格 | **M2×30 十字沉头自攻** |
| 数量 | 4 |
| 位置 | `HS_JOIN` = x=±19.2，z=3.5 / 58.5（四角贴侧壁） |
| 方向 | 从**右壳外表面**往左壳拧 |
| 右壳 | 沉窝 φ4.4×90° + φ2.4 过孔，穿外壁并沿新增导向柱一路到分模面，**共 23mm** |
| 左壳螺柱 | 外径 φ4.4，长 9mm，底孔 φ1.7 深 8.5mm |
| 螺纹啮合 | 7mm |

> **为什么这么长**：闸体是 46mm 宽的左右对开壳，分模面在正中央，螺丝天然要跨过半个壳体（23mm）才够得到对面的螺柱。M2×30 自攻比较细长，拧的时候**必须先用手扶正再上电动批**，斜着拧一定会顶裂导向柱。
> 若买不到 M2×30，可改用 **M2×35 截短** 或 **M2.5×30**（改 M2.5 需把 `SCREW_CLR` 改 2.9、`BOSS_PILOT` 改 2.1、`HEAD_D` 改 5.4 后重新导出）。

### 4. 转毂 ↔ 闸杆 A（横穿夹紧）

| 项 | 值 |
|---|---|
| 规格 | **M2×10 十字盘头自攻** |
| 数量 | 1 |
| 位置 | 距闸杆根部 6mm，沿装配 Y 向穿过闸杆 **5mm 窄边** |
| 转毂 | 两侧壁各 2.75mm，均为 φ2.4 **过孔**（不咬牙） |
| 闸杆 A | φ1.7 底孔，啮合 5mm |
| **长度不可超 10mm** | 转毂内侧面距闸体外壁只有 1mm，12mm 的螺丝会顶到闸体上，闸杆一转就刮壳 |

> 这是整机唯一的主受力螺丝：闸杆的全部重量和电机扭矩都从这里过。转毂建议树脂/PETG 100% 填充，装配时螺丝拧到"手感发紧"即可，**别用电动批**，会直接把 φ1.7 底孔撕开。

### 5. 闸杆 A ↔ 闸杆 B（插榫对接）

| 项 | 值 |
|---|---|
| 规格 | **M2×6 十字盘头自攻** |
| 数量 | 1 |
| 位置 | 距 B 段端面 10mm |
| 闸杆 B | φ2.4 过孔，穿 5mm 全宽 |
| 闸杆 A 插榫 | φ1.7 底孔，**啮合只有 2.1mm**（插榫壁厚所限） |
| **长度不可超 6mm** | 闸杆总宽只有 5mm，8mm 的螺丝会从背面戳出来 |

> 啮合 2.1mm 偏浅，属于"能用但别反复拆"。对接处建议螺丝 + 一滴 502 双保险。

### 6. 微动开关固定（0° 与 90° 限位）

| 项 | 值 |
|---|---|
| 规格 | **M2×10 十字盘头自攻** |
| 数量 | 4（两只开关 × 2 孔） |
| 位置 | 左壳的**两块独立安装台**，孔距 `SW_SPACING` = **6.5mm**，半径 `SW_HOLE_R` = **14.6mm** |
| 底孔 | **径向长圆孔**：宽 φ1.7 × 长 4.7（=±1.5 可调），深 **4.5mm 盲孔** |
| 方向 | 从腔内（凸轮侧）往安装台里拧 |
| 长度算法 | 开关本体 5.8mm（ZIPPY DF-P1S）+ 啮合 4.2mm = 10mm |
| **长度不可超 10mm** | 底孔只有 4.5 深、外壁只剩 1mm，更长会顶穿闸体外表面 |

> **孔距是 6.5**（ZIPPY DF-P1S-1E-M-Z 官方规格书）。v2.6 按 KW12 的 9.5 建模，已作废。
> ⚠️ **长圆孔里自攻螺丝只咬两条长边**，咬合面积少一半左右。拧到手感发紧就停，别使劲。
> ⚠️ **先松着拧**，手动转转毂调到"凸起刚好压下、基圆刚好释放"再拧紧——这就是做成长圆孔的目的（规格书只给了 FP 的 Max 没给 Min）。

### 7. 遥控器上盖 ↔ 下壳

| 项 | 值 |
|---|---|
| 规格 | **M2×12 十字沉头自攻** |
| 数量 | 4 |
| 位置 | `RC_BOSS`（PCB 坐标）= **(−7.5, 14.2) (11, 14.2) (−14, −17.2) (14, −17.2)**；外壳坐标再 **+1.5** 到 y 上 |
| 上盖过孔 | φ2.4 通孔，**只穿 3mm 面板**——遥控器上盖<b>没有止口环</b> |
| 下壳螺柱 | 下段 φ6（承托肩，顶面 z=**7.1**），上段 φ4.4 穿过板边缺口，顶面 z=**22.8**；底孔 φ1.7 |
| 螺纹啮合 | 9mm |

> 🔴 **原来写的 (±23, ±9) 已作废。** 四个位置不是挑的，是在板边扫出来的空窗：板 57×33 塞进 59×36 的内腔只剩 1.5mm，螺柱必须啃进板子，而**四个板角一个都不能用**（分别切到 U2 的 6 脚焊盘、U1 下排焊盘、擦过 SW3 焊盘 0.45mm）。解法是板往 −Y 加宽 3mm 做一条纯安装边，四个缺口开在扫描验证过的空窗里。
> ⚠ **这四根柱子同时干三件事**：φ6 下段托住板底、φ4.4 上段穿过板边缺口做横向定位、顶面给上盖拧螺丝。**别把它当普通螺柱看**，装的时候要确认板子确实坐到了 φ6 肩上、四个缺口都套进去了。

### 8. 凸轮顶丝（把 `cam` 锁在转毂轴颈上）

| 项 | 值 |
|---|---|
| 规格 | **M2×8 十字盘头自攻**（推荐）或 M2×8 内六角无头机米 |
| 数量 | 1 |
| 位置 | 凸轮上**凸起正背面**的顶丝凸台，径向顶在轴颈的键面上 |
| 底孔 | φ1.7，从凸台外圆 r=11 到键面 r=3.15，**可用 7.85mm** |
| 拧的方向 | 闸杆放到**落杆位（0°）**时顶丝正对闸体前面板的 **φ3 进入孔**，长柄小螺丝刀从孔外捅进去拧 |

> **为什么要开那个进入孔**：顶丝是径向的，而闸体的开口在分模面（+Y 方向），伸手够不着。
> **为什么顶丝凸台长在凸起背面**：转毂 0~90° 全程里凸起扫 +X/+Z（两只开关在那儿），凸台就永远扫 −X/−Z 那个空象限，不会打架。
> ⚠️ **角度不靠顶丝定**：凸轮的 D 形孔配轴颈上的键面，只有一个方向能套进去，套进去就是对的。顶丝只负责**轴向锁死**——而它是转毂唯一的轴向固定（拧紧后往外拔会被轴承凸台挡住），**务必拧紧并点螺纹胶**。
> v2.6 那颗"顶电机 D 形轴"的顶丝已删除：它落在局部 z=19，正好是凸轮盘现在坐的位置，而且轴颈壁只有 2.1mm，咬不住。

### 9. 承载底板固定

| 项 | 值 |
|---|---|
| 规格 | **M2×5 十字盘头自攻** |
| 数量 | 4 |
| 位置 | **(−82, ±27) 和 (+26, ±27)**（PCB 定稿的安装孔坐标）|
| 板上过孔 | φ2.2 非金属化孔（EDA 实读 `["ROUND", 86.6142]` mil = 2.2000）|
| **铜箔避让** | 🔴 **孔心到任何非 GND 铜箔 ≥ 2.5mm**（M2 盘头 φ3.5~4.0 → 半径 2.0，加 0.5 位置公差）|
| 托盘支撑柱 | 外径 φ4.4，顶面 z=4，底孔 φ1.7 深 3.4mm（底部留 0.6mm 不打穿） |
| 螺纹啮合 | 3.4mm |
| **长度不可超 5mm** | 底孔只有 3.4mm 深，再长就把托盘 2mm 地板顶穿了 |

> 啮合 3.4mm 对 M2 偏浅，但底板几乎不受力，够用。柱子已经从 z=0 整段长起（吃穿地板厚度）才凑出这 3.4mm——只从 z=1 起长的话只有 2.5mm。

> 🔴 **「铜箔避让」这条是 2026-08-15 复核补的，不是原设计要求。** 原来 `(−82, 27)` 那个孔旁 1.50mm 处走着 `VBAT_SW`（拨动开关之后的电池正极，全程无限流），而四个孔全落在 GND 覆铜区内 —— **M2 盘头会同时压住 VBAT_SW 和 GND，中间只隔一层阻焊**，拧紧压破阻焊就是电池对地短路。已把走线拐角从 x=−80 挪到 −78.5，净距 1.50 → **3.00mm**。
> **教训**：孔位表怎么查都查不出这个，因为问题不在孔里、在**螺丝头投影范围内**。

### 10. 转毂配重（非螺丝）

| 项 | 值 |
|---|---|
| 规格 | **M5 六角螺母，碳钢镀锌（别买不锈钢，密度低）** |
| 数量 | 1～2 |
| 位置 | 转毂 −X 端配重仓，**从端面滑入**（v2.3 才把这个仓做成真的开口，v2.2 是悬在实体外面的） |
| 仓尺寸 | **10(X) × 10(Y) × 7(Z) mm**，v3.3 随配重端削短 3mm 一起前移，仍从 −X 端开口 |

> 塞进去后点一滴热熔胶或 502 固定，否则闸杆一抬就掉出来。

> ⚠ **别对配重抱期望。** 算过一笔：M5 螺母约 1.6g、力臂 9mm → **14 g·mm**；而闸杆 300×5×8 的 PLA 约 15g、质心在 150mm → **2250 g·mm**。配重只有闸杆力矩的 **0.6%**，基本平衡不了什么，全靠电机拿住。想真配平得用铅或加长力臂，但力臂一长抬到竖直时就会撞上盖（v3.3 削短 3mm 就是为了让开，现在净距 4.0mm）。

---

## 三、不需要螺丝的地方（别多买）

| 部位 | 固定方式 |
|---|---|
| ESP32-S3-DevKitC-1 / TP4056 / 升压 / DRV8833 / 蜂鸣器 | v2.4 起全部焊在承载底板上，托盘不再给它们做限位柱。板子本身用上面第 9 条的 4 颗 M2×5 拧死 |
| N20 电机 | 穿过四道立筋上的 10.8×12.8 方孔，**靠两道压筋（单边过盈 0.15mm）夹紧**。推进去会被蹭平，发紧是正常的 |
| 103450 锂电 | 三条围挡 + 内壁挡住第四边；顶面离上盖 7mm，建议垫 EVA 泡棉防窜动 |
| **遥控器承载板** | **没有安装孔**。横向靠四根柱子卡在板边缺口里、向下靠 φ6 承托肩托住、向上靠上盖背面的**四条压条**压住，三者缺一板子就会窜 |

需要额外准备：**EVA 泡棉**（电池压紧）、**热熔胶枪或 502**（配重、走线固定）。

> ⚠️ **排母买低背 5.0mm**（U1/U2/U4 三处）。不是螺丝但同属采购卡点：标准 8.5mm 排母叠高 15.67mm，超净空 2.3mm 装不进去。详见 `道闸玩具_底板机械约束_v1.md` §一。

---

## 四、给打印/装配的三条提醒

1. **底孔一律 φ1.7，不要自己扩孔。** 觉得拧不动是正常的——自攻螺丝就是靠挤压塑料成型的。扩到 φ2 以上就彻底没有咬合力了。
2. **螺柱外径只有 φ4.4**（= 2.2 × M2），是 M2 自攻的下限。如果打印材料偏脆（比如某些高速 PLA、光敏树脂），第一次拧就可能沿层间裂开。真裂了就把 `daozha.scad` 里的 `BOSS_OD` 从 4.4 改成 5.0 重新导出，四周都有余量，不会撞到别的特征。
3. **沉窝已按标准 90° 建模**（v2.2 是 67°，螺丝头会卡在孔口翘起来）。买沉头螺丝务必确认是 90° 锥角，市面上还有 82° 的美制规格，会坐不平。

---

## 五、变更记录

| 版本 | 日期 | 说明 |
|---|---|---|
| v1 | 2026-08-11 | 首版，对应 CAD v2.3 |
| v1.1 | 2026-08-12 | 对齐 CAD v2.5：闸体固定 M2×12→M2×10；新增底板固定 M2×5 ×4；角螺柱位置与螺柱高度更新；补排母高度提醒 |
| v1.2 | 2026-08-12 | 对齐 CAD v2.6；标注哪些长度依赖元件实测尺寸 |
| v1.3 | 2026-08-14 | 对齐 CAD **v3.0**：角螺柱/闸体固定点/底板安装孔全部换成新坐标；微动开关改 6.5 孔距 + 径向长圆孔 + 4.5 盲底孔；顶丝改为**凸轮顶丝 M2×8**（原转毂顶丝删除）。**总数仍是 27 颗** |
| v1.4 | 2026-08-15 | 对齐 CAD **v3.3**。**总数仍是 27 颗，规格一颗没变**，改的全是位置和说明：① 闸体转 90°、固定点 (55±15)→**(51.5±15)**，补朝向提醒；② 承载底板 −X 两角更正为 **45°×7 倒角**（原写 5×5 方缺口，与 EDA 实际板框不符）；③ 遥控器上盖螺柱位置**全部替换**（原 (±23,±9) 作废），补「一根柱子干三件事」说明，过孔更正为只穿 3mm（无止口环）；④ 承载底板固定新增**铜箔避让 ≥2.5mm** 判据（原写「沉铜环 φ4.5 以内不要走线」不足以防螺丝头短路）；⑤ 配重仓尺寸/位置更新并补力矩实算；⑥ N20 固定方式更正为**压筋夹紧**（原写「合壳即夹紧」，实际四道立筋是完整方孔，合壳不产生压紧力）；⑦ 补遥控器承载板的固定方式 |

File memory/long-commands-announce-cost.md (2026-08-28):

---
name: long-commands-announce-cost
description: 跑几分钟以上的命令（冷编译、全量自检）前先说清要多久，否则用户看不到进展会以为卡住了
metadata:
  type: feedback
---

跑耗时数分钟的命令前，**先用一句话说清"这步大概多久、为什么慢"**，或者放后台跑。

2026-08-28 固件首次编译：ESP-IDF 冷编译 1087 个目标文件，一轮几分钟，我连跑了 set-target + build 且没作声。用户中途打断问「你在干什么为什么还没有编译完成」——**而主机那次其实已经编完了**，用户没看到而已。

**Why**：工具输出只给我看，不可靠地显示给用户。长命令 + 不出声 = 用户面前是纯静默，跟卡死没有区别。

**How to apply**：
- 本项目已知的长命令：`idf.py build`（冷编译几分钟）、`cad/run_check.ps1`（52 条用例约 25 分钟，见 [[daozha-toy-scope]]）
- 开跑前一句：「冷编译 1087 个文件，几分钟」
- 更长的（十几分钟以上）直接 `run_in_background`，别占着对话
- 一步做完就报一次结果，别攒着几步一起报 —— 用户判断"是不是卡住了"靠的是这个

配套：[[verify-selectively]]（别烧 token 跑全流程）。

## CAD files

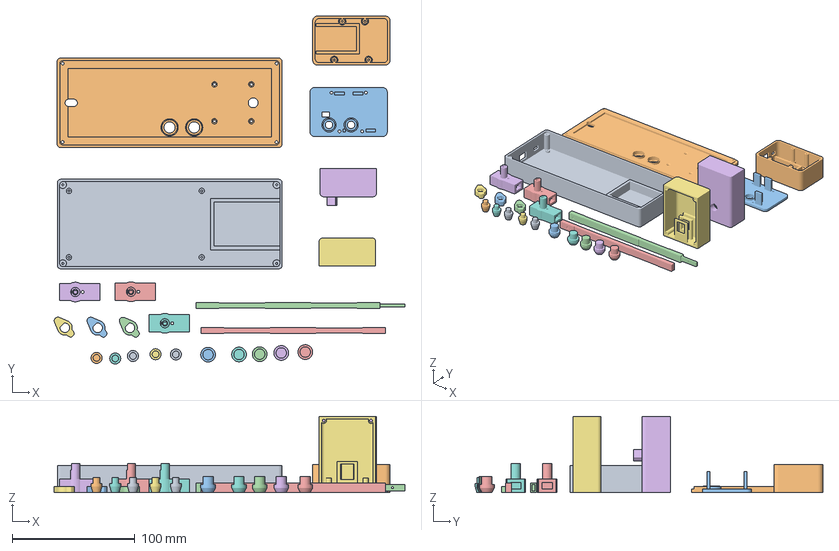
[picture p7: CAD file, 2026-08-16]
cad/daozha.3mf
285.2 x 283.1 x 62.0 mm
base_tray.stl
base_top.stl
rc_top.stl
bar_a.stl
bar_b.stl
hub.stl x 3
cam.stl x 3
btn_cap.stl x 5
rc_btn_cap.stl x 5
rc_bottom.stl
house_l.stl
house_r.stl

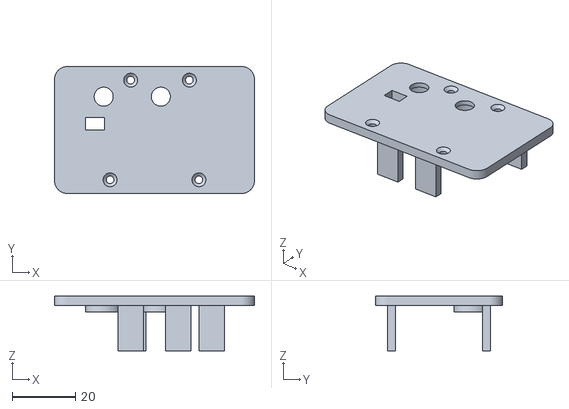
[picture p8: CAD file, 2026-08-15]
cad/stl/rc_top.stl
63.0 x 40.0 x 17.3

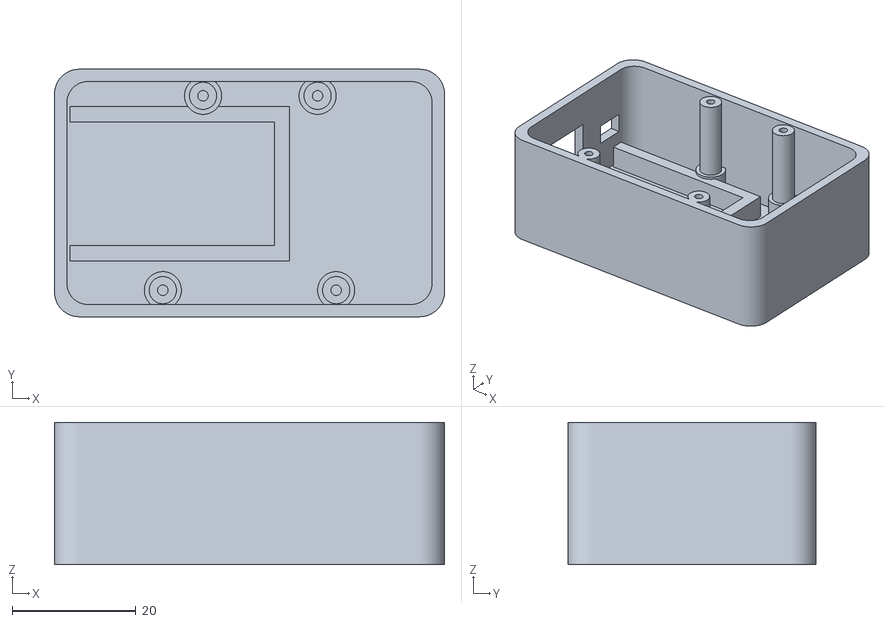
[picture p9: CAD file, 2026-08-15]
cad/stl/rc_bottom.stl
63.0 x 40.0 x 23.0

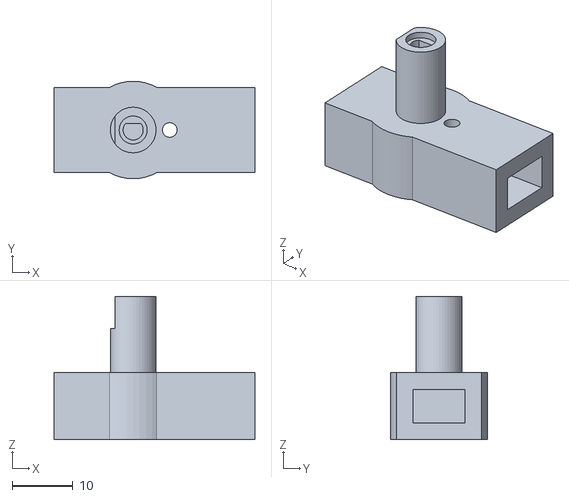
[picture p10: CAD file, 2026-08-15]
cad/stl/hub.stl
33.0 x 16.0 x 23.5

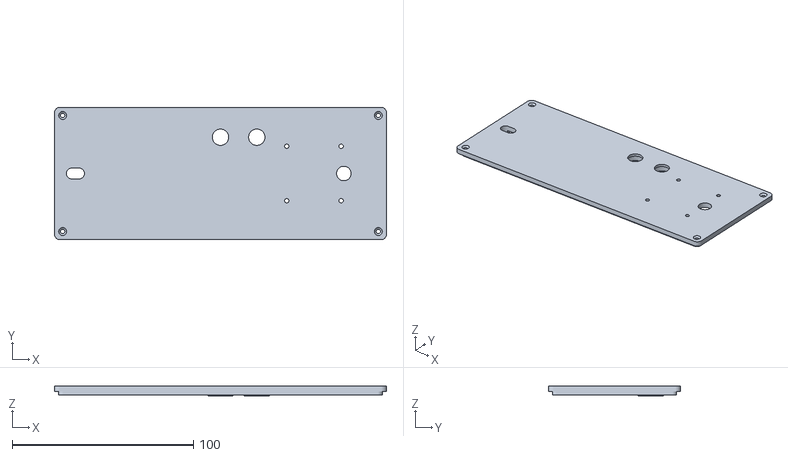
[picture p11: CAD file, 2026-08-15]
cad/stl/base_top.stl
183.0 x 73.0 x 5.50

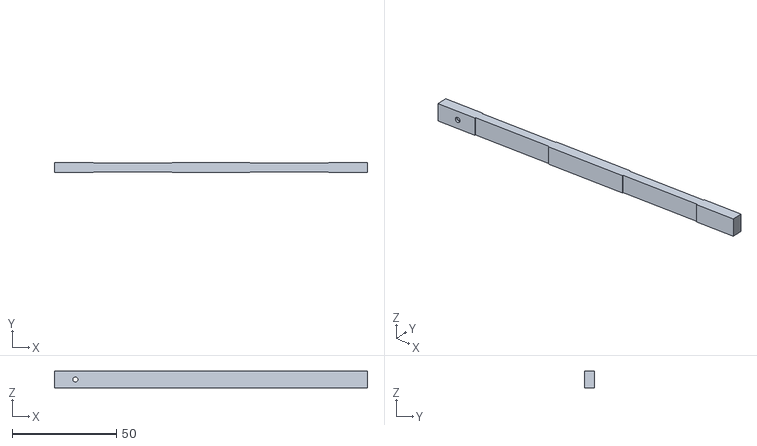
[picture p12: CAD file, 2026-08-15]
cad/stl/bar_b.stl
150.0 x 5.00 x 8.00

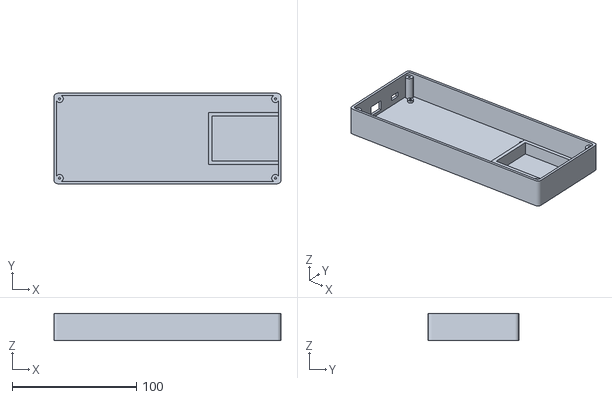
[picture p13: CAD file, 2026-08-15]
cad/stl/base_tray.stl
183.0 x 73.0 x 22.0

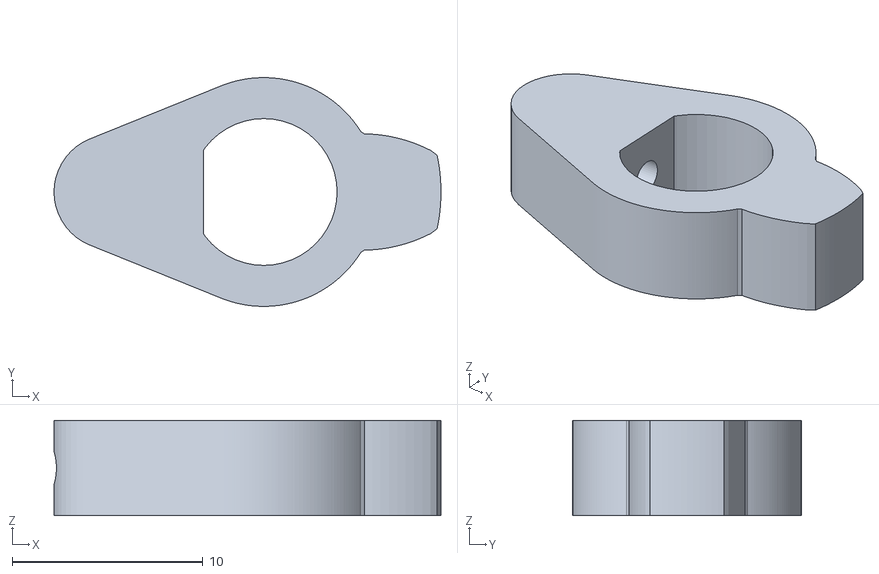
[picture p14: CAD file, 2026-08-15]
cad/stl/cam.stl
20.3 x 12.0 x 5.00

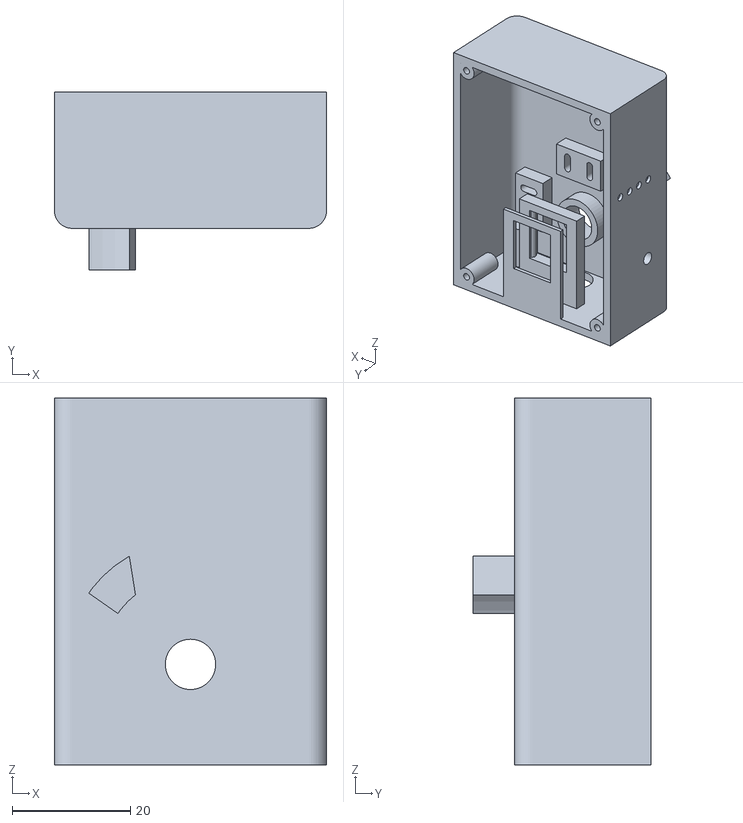
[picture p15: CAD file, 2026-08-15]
cad/stl/house_l.stl
46.0 x 30.0 x 62.0

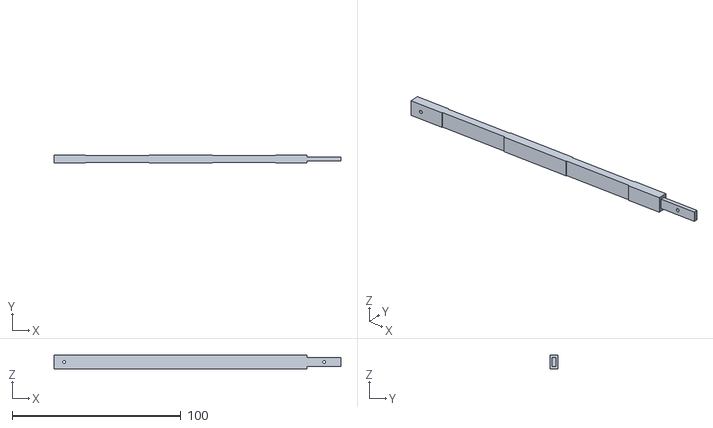
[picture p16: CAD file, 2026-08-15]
cad/stl/bar_a.stl
170.0 x 5.00 x 8.00

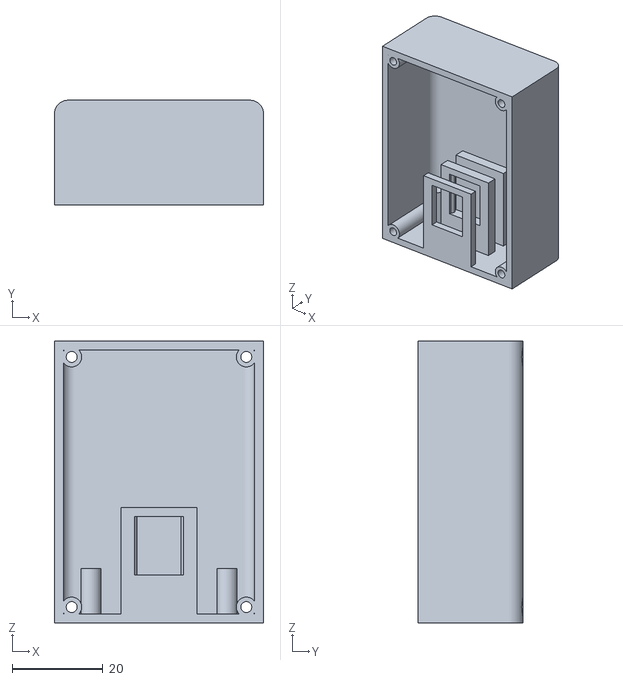
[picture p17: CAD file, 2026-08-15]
cad/stl/house_r.stl
46.0 x 23.0 x 62.0

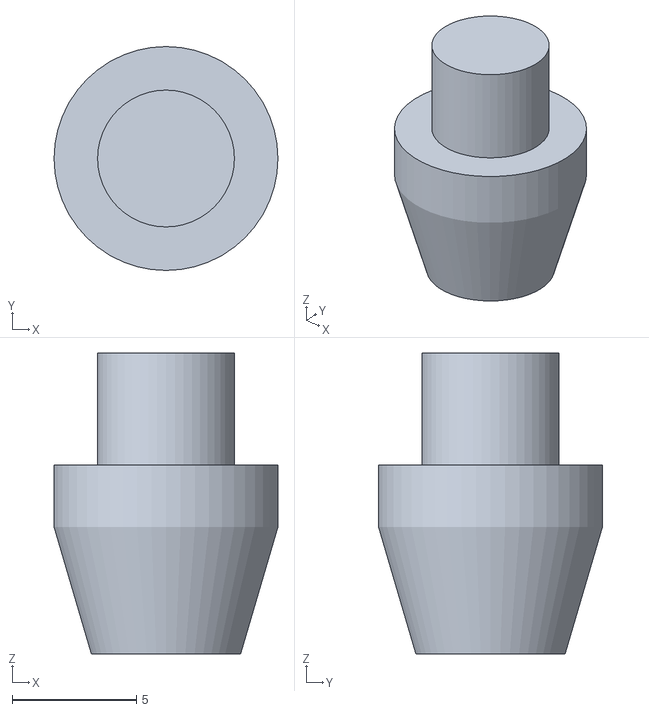
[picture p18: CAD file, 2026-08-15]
cad/stl/rc_btn_cap.stl
9.00 x 9.00 x 12.1

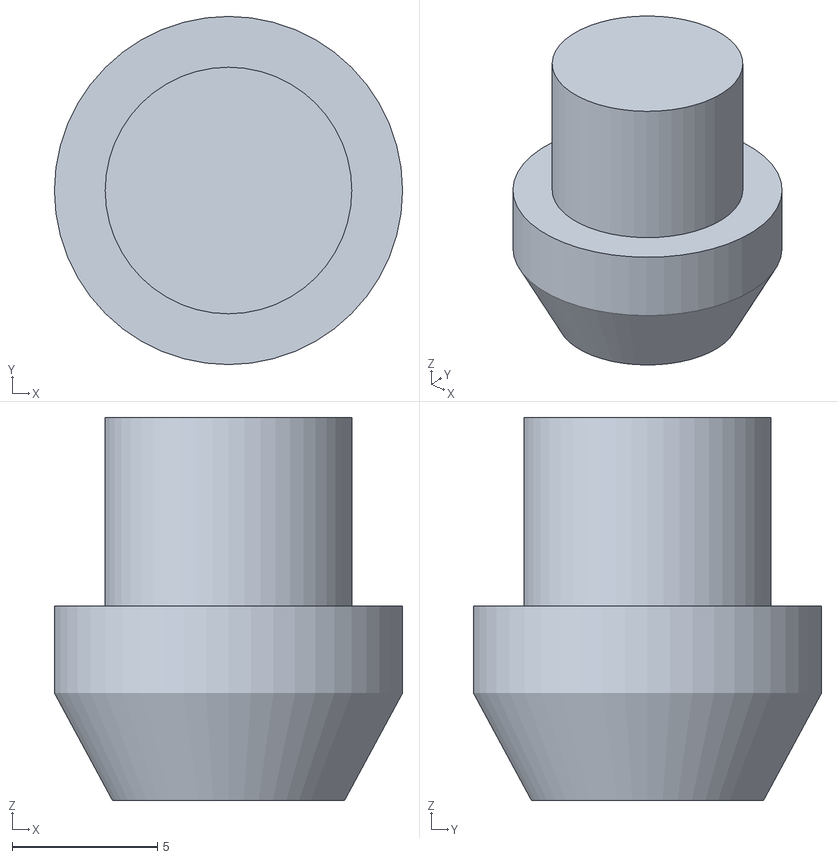
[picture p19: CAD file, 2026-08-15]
cad/stl/btn_cap.stl
12.0 x 12.0 x 13.2

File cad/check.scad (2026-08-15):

// 装配性自检: 每个 t 出一个几何体。
//   期望 EMPTY 的 = 不干涉 / 孔真的通 / 装得进
//   期望 NON-EMPTY 的 = **阳性对照**, 证明检测本身有效
// ⚠ 没有阳性对照的自检等于没做 —— 检测失效了你也不知道。v2.2 就是这么栽的。
//
// 跑法: openscad -D t=NN -o out.stl check.scad, 看输出的 Vertices/facets;
//       更省事的是 cad/run_check.ps1, 它把全部用例跑一遍并比对期望值。
include <daozha.scad>
part = "none";          // 覆盖掉源文件的顶层出图
t = 1;

PROBE   = 2.0;          // 探针直径, 略小于 SCREW_CLR=2.4 (验 M2 过孔)
PROBE_S = 1.4;          // 细探针, 略小于 BOSS_PILOT=1.7 (验自攻底孔)
                        // ⚠ 用 φ2.0 去探 φ1.7 的底孔当然探不通, 那不是缺陷
BUDGET  = TRAY_H - PCB_Z;  // 板面以上可用高度, 随 BASE_H 自动跟随 (16.4)
MIC_T_CHK = 0.9;        // 麦克风板厚 1.0, 求交时缩 0.1 免得共面接触

/* ⚠⚠ 写用例的铁律: **不许留共面接触**。
   两个实体面贴面求交, CGAL 给的是一张零体积薄片, 导出 STL 有几百个三角形,
   看文件大小会被判成"非空"。v3.0 第一轮就是这么冒出 5 条假失败:
   托盘顶面 vs 上盖背面(z 22..22)、电芯 -X 面 vs 挡边(x 36..36)、
   转毂夹持段顶面 vs 判定用的半空间(z 11..11)。
   所以凡是"应该刚好贴上"的地方, 一律把其中一个错开 0.01~0.05 再求交。      */

module probe_z(x, y, z0, z1) translate([x, y, z0]) cylinder(d = PROBE, h = z1 - z0);
module probe_y(x, z, y0, y1) translate([x, y0, z]) rotate([-90, 0, 0]) cylinder(d = PROBE, h = y1 - y0);

// 闸体局部坐标下的转毂/凸轮, 闸杆抬到 a 度
module hub_at(a)
    translate([0, 0, PIV_Z]) rotate([0, -a, 0]) translate([0, 0, -PIV_Z])
        translate([0, HUB_Y_ABS, PIV_Z]) rotate([-90, 0, 0]) hub();
module cam_at(a)
    translate([0, 0, PIV_Z]) rotate([0, -a, 0]) translate([0, 0, -PIV_Z])
        translate([0, HUB_Y_ABS, PIV_Z]) rotate([-90, 0, 0])
            translate([0, 0, CAM_Z0]) cam();
// 微动开关本体实体 (12.70×6.60×5.80, 内面 r=9.85), 拧在安装台上
module sw_body(a) at_sw(a)
    translate([9.85, -6.35, YIN - 1.2 + SW_PAD_T]) cube([6.55, 12.7, 5.8]);
// 杠杆尖端的探片。放在 r=6.5 —— 即"杠杆已被压下 0.5mm"的位置, 而不是自由
// 位置 r=6.0: 贴基圆是相切, 又变成共面接触判不了。
// 凸轮扫过来时, 只要升程超过 0.5mm 这片就会被吃到。
module sw_lever(a) at_sw(a)
    translate([6.5, -2, CAM_Z0 + HUB_Y_ABS + 0.5]) cube([0.5, 4, CAM_T - 1]);

// --- 期望 EMPTY ---
// t=1 / t=2 (上下壳直接求交) 已删除: 贴合面共面, 出的是零体积薄片, 判不了。
// 它们的作用被 t=13 / t=14 (抬 0.01 脱开贴合面) 完全覆盖 —— 真有 >0.01 的
// 干涉那两条照样抓得到。
// 24/25: **支撑柱的自攻底孔是否对准承载底板的安装孔**。
//   CAD 里的 PCB 模型没画孔, 这条以前从来没验过 —— 柱心与板孔用的是同一个
//   常量 PCB_MNT, 但"用同一个常量"不等于"几何上真对得上"。
//   φ1.4 探针从板面之上一路探到柱底: 底孔 φ1.7 从 z=0.6 开始, 所以到 z=1 必须畅通。
if (t == 24) intersection() { base_tray();
    for (p = PCB_MNT) translate([p[0], p[1], 1]) cylinder(d = PROBE_S, h = 9); }
// 25: 阳性对照 —— 探针偏 1.5mm 必须撞在柱体上 -> NON-EMPTY
if (t == 25) intersection() { base_tray();
    for (p = PCB_MNT) translate([p[0] + 1.5, p[1], 1]) cylinder(d = PROBE_S, h = 9); }

if (t == 3) intersection() { base_top();
    for (p = BASE_BOSS) probe_z(p[0], p[1], -LIP_T-1, TOP_T+1); }
if (t == 4) intersection() { base_top();
    for (p = HS_BOSS) probe_z(HS_X_ABS+p[0], p[1], -LIP_T-1, TOP_T+1); }
// t=5 (遥控上盖螺丝孔) 已删除: RC_BOSS 改成 PCB 坐标后它没加 RC_PCB_DY 偏移,
//     而且 rc_top 已不带止口环。作用由 t=67 完全覆盖。
if (t == 6) intersection() {
    translate([HS_X_ABS,HUB_Y_ABS,BASE_H+PIV_Z]) rotate([-90,0,0]) hub();
    translate([HS_X_ABS, BAR_Y_ABS, BASE_H+PIV_Z-BAR_H/2]) bar_a(); }
if (t == 7) intersection() {
    translate([HS_X_ABS,HUB_Y_ABS,BASE_H+PIV_Z]) rotate([-90,0,0]) hub();
    probe_y(HS_X_ABS+BAR_PIN_X, BASE_H+PIV_Z, -40, -20); }
if (t == 8) intersection() { house_l(); house_r(); }
if (t == 9) intersection() { house_r();
    for (p = HS_JOIN) probe_y(p[0], p[1], 0, HS_W/2+1); }
// 闸杆上是 φ1.7 自攻**底孔**(不是过孔), 只能用细探针
if (t == 10) intersection() {
    translate([HS_X_ABS, BAR_Y_ABS, BASE_H+PIV_Z-BAR_H/2]) bar_a();
    translate([HS_X_ABS+BAR_PIN_X, -40, BASE_H+PIV_Z]) rotate([-90,0,0])
        cylinder(d = PROBE_S, h = 20); }

// 13/14: 把上盖抬 0.01mm 脱开贴合面, 排除"共面接触"造成的零体积假阳性
if (t == 13) intersection() { base_tray(); translate([0,0,TRAY_H+0.01]) base_top(); }
if (t == 14) intersection() { rc_bottom(); translate([0,0,RC_H-RC_TOP_T+0.01]) rc_top(); }

// 15: 横穿螺丝同轴性 —— φ1.4 探针要同时穿过转毂 φ2.4 过孔和闸杆 φ1.7 底孔
if (t == 15) intersection() {
    union() {
        translate([HS_X_ABS,HUB_Y_ABS,BASE_H+PIV_Z]) rotate([-90,0,0]) hub();
        translate([HS_X_ABS, BAR_Y_ABS, BASE_H+PIV_Z-BAR_H/2]) bar_a();
    }
    translate([HS_X_ABS+BAR_PIN_X, -40, BASE_H+PIV_Z]) rotate([-90,0,0])
        cylinder(d = 1.4, h = 20); }
// 16: 转毂**连同凸轮**转起来不能刮到闸体 (含新增的轴承凸台和两块安装台)
if (t == 16) intersection() {
    union() for (a = [0, 30, 60, 90]) { hub_at(a); cam_at(a); }
    union() { house_l(); house_r(); } }

// --- 阳性对照, 期望 NON-EMPTY ---
// 11: 右壳导向柱确实存在 (在 y=2..20 段上, 螺丝孔外圈应有料)
if (t == 11) intersection() { house_r();
    translate([HS_JOIN[0][0], 2, HS_JOIN[0][1]]) rotate([-90,0,0]) cylinder(d = BOSS_OD, h = 18); }
// 12: 闸杆若按错误姿态(宽面朝下, 绕 X 转 90°)插入, 必须插不进去
if (t == 12) intersection() {
    translate([HS_X_ABS,HUB_Y_ABS,BASE_H+PIV_Z]) rotate([-90,0,0]) hub();
    translate([HS_X_ABS, BAR_Y_ABS, BASE_H+PIV_Z]) rotate([90,0,0])
        translate([0,0,-BAR_H/2]) bar_a(); }

// 17/18: 开关安装底孔。v3.0 改成了**盲孔**(深 4.5, 外壁留 1mm), 所以
//   17 = 外壁皮层里必须**有料** (NON-EMPTY, 阳性对照: 没打穿)
//   18 = 底孔本身必须是通的 (EMPTY)
// v2.6 那组 17/18/19 判的是"打没打穿", 且被止挡筋污染, 已作废。
if (t == 17) intersection() { house_l();
    for (a = SW_ANG) at_sw(a) for (s = [-1,1])
        translate([SW_HOLE_R, s*SW_SPACING/2, -22.8]) cylinder(d = 1.4, h = 0.7); }
if (t == 18) intersection() { house_l();
    for (a = SW_ANG) at_sw(a) for (s = [-1,1])
        translate([SW_HOLE_R, s*SW_SPACING/2, -21.5]) cylinder(d = 1.4, h = 4.0); }

// 55/56: 阳性对照 —— **两块安装台真的都在**。
//   t=17/18 只验了"底孔没打穿外壁"和"底孔是通的", 但安装台整块不存在时这两条
//   照样过(没有料可求交)。所以要单独验"孔的四周有料", 而且两块必须分开验 ——
//   合在一个用例里, 只要有一块在就非空了。
module pad_probe(a) at_sw(a)
    for (s = [-1,1]) translate([SW_HOLE_R, s*SW_SPACING/2, YIN - 1.2 + SW_PAD_T - 2])
        cylinder(d = 6, h = 1.5);
if (t == 55) intersection() { house_l(); pad_probe(0); }
if (t == 56) intersection() { house_l(); pad_probe(90); }

/* ===== v2.4 排布自检 ===== */
// 20: 电芯实体 vs 托盘内部特征 (角螺柱/围挡/支撑柱) —— 期望 EMPTY
// 电芯六个面都缩 0.05: 底面坐在地板上、-X 面贴着挡边, 不缩就是共面接触
if (t == 20) intersection() { base_tray();
    translate([BAT_X0 + 0.05, -BAT_W/2 + 0.05, WALL + 0.05])
        cube([BAT_L - 0.1, BAT_W - 0.1, BAT_T - 0.1]); }
// 21: 承载底板 vs 托盘 (抬 0.01 脱开支撑柱贴合面) —— 期望 EMPTY,
//     验证 -X 两角的 45°×7 倒角(PCB_CHAMFER, 与 EDA 板框逐点一致)避开角螺柱。
//     ⚠ 曾经这里建成 5×5 方缺口, 挖掉的料比真板多, 于是一直"通过"——
//        偏乐观的错误比报错更危险, 见 daozha-toy-scope 教训 #5。
if (t == 21) intersection() { base_tray();
    translate([0,0,WALL+PCB_SO+0.01]) linear_extrude(PCB_T) pcb_outline(); }
// 22: 板面以上 (BUDGET-0.1) 元件包络 vs 上盖 —— 期望 EMPTY, 验证中央区净高够
//     扣掉两个按键帽导向凸台的地盘: 那两块本来就是留给帽子的, 不算净空冲突
module envelope(h) difference() {
    intersection() {
        translate([0,0,PCB_Z]) linear_extrude(h) pcb_outline();
        translate([-LIP_IN_X, -LIP_IN_Y, 0]) cube([2*LIP_IN_X, 2*LIP_IN_Y, 40]);
    }
    for (b = BTN_POS) translate([b[0], b[1], 0]) cylinder(d = BTN_GUIDE_D + 1, h = 40);
}
if (t == 22) intersection() { translate([0,0,TRAY_H]) base_top(); envelope(BUDGET - 0.1); }
// 23: 阳性对照 —— 同样的包络加到 BUDGET+0.2 必须撞上盖(证明 22 不是白跑)
if (t == 23) intersection() { translate([0,0,TRAY_H]) base_top(); envelope(BUDGET + 0.2); }

/* ===== v2.6: 电机 / D 形轴 / 机械止挡 ===== */
// 真实 D 形轴实体(无间隙), 用来验证转毂孔
module d_shaft_solid(h) {
    intersection() {
        cylinder(d = SHAFT_D, h = h);
        translate([-SHAFT_D, -SHAFT_D, -1])
            cube([2*SHAFT_D, SHAFT_D + (SHAFT_FLAT - SHAFT_D/2), h + 2]);
    }
}
// 30: D 形轴插得进转毂 -> EMPTY
if (t == 30) intersection() { hub();
    translate([0,0,BORE_Z0]) d_shaft_solid(BORE_Z1 - BORE_Z0); }
// 31: 阳性对照 —— 整根 φ3 圆柱必须被 D 面挡住 -> NON-EMPTY
//     若这条变 EMPTY, 说明孔又退化成整圆, D 面失效, 轴会空转
if (t == 31) intersection() { hub();
    translate([0,0,BORE_Z0]) cylinder(d = SHAFT_D, h = BORE_Z1 - BORE_Z0); }
module motor_box(grow = 0)
    translate([-MOT_W/2 - grow, MOT_Y0, PIV_Z - MOT_H/2 - grow])
        cube([MOT_W + 2*grow, MOT_L, MOT_H + 2*grow]);
// 32: N20 机身 10×12×MOT_L 装得进电机座 -> EMPTY
//     ⚠ 必须传 crush=false: 压筋是**故意**过盈的, 带着它测这条永远非空。
//     这条测的是"隧道本身尺寸对不对", 压筋归 t=88/89 管。
if (t == 32) intersection() { motor_seat(false); motor_box(); }
// 33: 阳性对照 —— 旧版假设的 12.5 方形必须装不进 -> NON-EMPTY
if (t == 33) intersection() { motor_seat(false);
    translate([-12.5/2, MOT_Y0, PIV_Z - 12.5/2]) cube([12.5, MOT_L, 12.5]); }
// 34/35: 机械止挡。闸杆摆到 ang, 与止挡块求交。
//        t=34 用 STOP_ANG-1 -> 必须 EMPTY;  t=35 用 STOP_ANG+1 -> 必须 NON-EMPTY
if (t == 34) intersection() { hub_at(STOP_ANG - 1); stop_rib(); }
if (t == 35) intersection() { hub_at(STOP_ANG + 1); stop_rib(); }

/* ===== 遥控器 (v3.1, 按 PCB 定稿反推) =====
   PCB 坐标 -> 外壳坐标只差 Y 偏移 RC_PCB_DY, 下面一律用 rcx() 换算,
   免得两套坐标混用。                                                     */
/* 承载板实体。**必须带四个螺柱缺口** —— 螺柱本来就是从缺口里穿上去的,
   拿一块没缺口的方板去求交, 撞的是我自己画的测试模型, 不是设计缺陷。
   (第一版就是这么误报的。) shrink 用 offset 让整圈缩进, 脱开贴合面。 */
module rc_pcb_solid(shrink = 0, dz = 0)
    translate([0, RC_PCB_DY, RC_PCB_Z0 + dz])
        linear_extrude(RC_PCB_T) offset(delta = -shrink) rc_pcb_outline();
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

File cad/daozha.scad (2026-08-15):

// =====================================================================
//  道闸玩具 v3.0 · 参数化结构件
//  依据: 道闸玩具_元器件尺寸基准_v1.md (元件尺寸唯一事实源)
//        道闸玩具_底板机械约束_v1.md §七之二 (PCB 定稿坐标)
//
//  v2.6 -> v3.0 (解冻。元器件全部实测落地 + PCB 定稿, 12 项积压改动一次做完):
//    [1]  底座 150×55×22 -> **183×73×25**; 承载底板 87×47 -> **120×65**
//         (根因: U4 实测 37mm 长, 老板子放不下。见机械约束 §七之二)
//    [2]  电池仓按成品 51×34×10 重排, 引线朝 -X
//    [3]  转毂拆成 hub(主体) + cam(凸轮盘) —— 一整件穿不过 φ8.5 壁孔
//    [4]  壁孔内侧加 φ12×4 凸台, 轴承长度 2 -> 6mm
//    [5]  电机 MOT_L 25.2 / SHAFT_L 10 / SHAFT_FLAT 2.45 + φ4×0.7 轴根凸台让位
//    [6]  凸轮升程 3.3 (PT Max 反推), 凸起两端各加 18° 过渡斜坡 (原为直角台阶)
//    [7]  开关托板整块方板 -> 两块独立安装台; 底孔改**径向长圆孔**(±1.5 可调)
//    [8]  按键孔 φ6.5 -> φ9 + 背面沉孔/导向凸台; 新增 btn_cap ×2
//    [9]  麦克风: 前面板内侧 φ15.4×1.2 圆窝 + 上下压舌
//    [10] 上盖: TP4056 充电灯观察孔; Type-C / 拨柄开口对准 PCB 实际坐标
//    [11] 遥控器: 补拨动开关开口 + 板载蓝灯观察孔; 电池仓按含保护板 7×21×32
//    [12] 文件头版本号归位
//
//  坐标约定 (OpenSCAD Z 朝上):
//    X  = 前后。-X = 长脚侧(按键 / Type-C)，+X = 闸杆伸出侧(道路)
//    Y  = 车辆行驶方向 (对应设计文档里的 Z 轴)
//    Z  = 高度，Z=0 为底座底面
//
//  v2.1 -> v2.2 修复:
//    - 闸体内腔挖穿顶面 -> 补回 2mm 顶盖
//    - 闸体底面被整个切开导致螺柱/托架悬空 -> 补回 2mm 底板 + 走线孔
//    - 微动开关座悬空 -> 改为贴内壁的整体托板
//    - 底座/遥控器内部特征被内腔减掉 -> 移出 difference() 之后再并集
//    - 电机托架 X 未居中、让位孔够不到 -> 重建
//    - 机械止挡筋是空块 -> 补建
//    - 新增 layout 视图, 可看内部元件排布
//
//  v2.2 -> v2.3 修复 (装配性):
//    [1] base_top / rc_top 的螺丝孔不是通孔 —— 沉头孔只从 z=-1 开始, 而两块
//        盖板背面都有 2mm 止口凸台(z=-2..0), 于是孔底留了 1mm 皮, 打完还得手工
//        捅穿。改成 csk(h, deep) 连止口一起打穿; 闸体固定孔的沉窝也移到止口
//        真正的背面 z=-2, 否则沉头埋在实体里。顺带把沉窝改成标准 90°。
//    [2] base_tray / rc_bottom 的螺柱顶面做到了与外沿等高(17), 没给上盖背面
//        2mm 止口让位 -> 上下盖压根扣不上。螺柱顶面下移到 外沿 - LIP_T - 0.2。
//    [3] hub 闸杆插槽的长宽装反了 —— 槽在装配坐标里是"竖 5.5 / 横 8.5",
//        闸杆(宽5 高8)只能宽面朝下躺着装; 横穿螺丝也跟着穿在竖直方向。
//        改为 竖 8.5 / 横 5.5, 螺丝改沿装配 Y 向穿杆的 5mm 窄边 —— 闸杆窄面
//        朝下、8mm 立起来受弯。同时把插槽加深到 20mm, 补上根本没落在实体里的
//        配重仓。
//    [4] 附带发现: house_r 侧没有对拧导向柱, 螺丝要在 21mm 空腔里悬空,
//        补 φ4.4 导向柱从 +Y 内壁撑到分模面。
//    [5] 闸杆自攻底孔 φ1.9 对 M2 太松 -> 统一为 BOSS_PILOT(1.7)。
//
//  紧固件规格见: ../道闸玩具_紧固件清单_v1.md
// =====================================================================

// GUI 里改这个字符串:
part = "assembly";
// assembly | explode | layout | base_tray | base_top | house_l | house_r | hub
// cam | btn_cap | bar_a | bar_b | rc_bottom | rc_top

// 命令行用数字 (避开 shell 传引号的麻烦):
//   openscad -D p=3  -o stl/house_l.stl daozha.scad
//   openscad -D p=13 -o png/explode.png --imgsize=1600,1200 daozha.scad   <- 爆炸图
p = 0;
PARTS = ["assembly", "layout", "base_tray", "base_top", "house_l",
         "house_r", "hub", "bar_a", "bar_b", "rc_bottom", "rc_top",
         "cam", "btn_cap", "explode", "rc_btn_cap"];
sel = (p == 0) ? part : PARTS[p];

$fn = 48;

/* ============ 通用配合参数 ============ */
WALL       = 2.0;
GAP        = 0.25;
BOSS_OD    = 4.4;
BOSS_PILOT = 1.7;             // M2 自攻底孔 (塑件)
SCREW_CLR  = 2.4;             // M2 过孔
HEAD_D     = 4.4;             // M2 沉头沉窝口径 (实际头 φ3.8, 留 0.6 余量)
LIP_T      = 2.0;             // 上盖背面止口凸台高度 (base_top / rc_top 共用)
BOSS_CLR   = 0.2;             // 螺柱顶面相对止口底面的让空, 保证外沿先贴合

/* ============ 底座 ============ */
// v3.0: 150×55×22 -> 183×73×25。
// 长宽是被 PCB 逼大的 (U4 实测 37mm, 老板子 100×55 差 3.2mm 塞不下),
// 换算关系 BASE_L = 板长 + 63、BASE_W = 板宽 + 8, 见机械约束 §一。
// 高度 22 -> 25 是顺带把按键帽的行程/导向长度做够 (见 BTN_* 那段)。
// 转轴离地 42 由 PIVOT_ABS 反推自动保持, 杆顶仍 46mm, 锁定约束不破。
BASE_L = 183;  BASE_W = 73;
BASE_H = 25;
TOP_T  = 3;
TRAY_H = BASE_H - TOP_T;      // 22
BASE_R = 3;

// 内腔: x ±89.5, y ±34.5, 地板面 z=2, 天花板(上盖背面) z=22
// v2.3 的"止口"是 rbox 生成的**实心板**, 整块压在天花板下 2mm,
// 把内腔净高砍掉 2mm —— ESP32 装不进去的真因。改成环形。
LIP_W    = 6.5;                                    // 止口环宽
LIP_IN_X = (BASE_L - 2*WALL - 2*GAP)/2 - LIP_W;    // 82.75
LIP_IN_Y = (BASE_W - 2*WALL - 2*GAP)/2 - LIP_W;    // 27.75
// => 中央净空区 x ±82.75 / y ±27.75, 净高 20mm; 环下方 18mm
//    板面(5.6)以上: 中央区 16.4mm / 环下方 14.4mm

// 角螺柱: 必须待在止口环正下方(沉窝才有料可埋), 且要让开电池。
// φ6 是为了嵌进 x=±89.5 / y=±34.5 两侧内壁, 否则细高柱立不稳。
// PCB 的 -X 两角开 5×5 缺口让开这两根。
CORNER_OD = 6.0;
BASE_BOSS = [[-87, 32], [-87, -32], [87, 32], [87, -32]];

// 按键 [x, y] —— **PCB 定稿值, 不是结构挑的**(机械约束 §七之二):
//   SW2(落杆) = (0, +20)、SW1(起杆) = (+20, +20), 同一 Y、间距 20。
// 校核: 背面沉孔 φ12.5 -> y 13.75..26.25, 止口环内缘 27.75 ✓ 不撞环;
//       DevKit 顶边在 y=+5.97 ✓ 让开。
BTN_POS = [[0, 20], [20, 20]];

// 上盖按键孔三段 (v3.0: 顶杆够不到盖面, 必须配打印按键帽 btn_cap)
BTN_D       = 9.0;    // 通孔 (帽柄 φ8.5 穿过)
BTN_CB_D    = 12.5;   // 背面沉孔 (挡住帽的 φ12 法兰, 防脱)
BTN_CB_T    = 1.5;    // 沉孔吃进 3mm 面板的深度
BTN_GUIDE_H = 2.5;    // 背面再加的导向凸台高度 -> 沉孔总深 4.0
BTN_GUIDE_D = 14.0;   // 导向凸台外径
BTN_SW_H    = 12.0;   // 轻触开关总高 (6×6×12, 底座 3.5 + 柄 8.5)

/* 前端面开口。y 全部对准 PCB 上器件的实际坐标 (2026-08-15 从 EDA 复核过):
     U3 TP4056 在 (-74.8, -6), 本体前沿(Type-C 座口) x = -88.23
     SW3 拨动开关在 (-84.1, +17), 拨柄尖 x = -93.51

   🔴 USB 开口必须按**插头的塑料头**开, 不是按金属壳开。
   沿 -X 数过去: 外壁面 -91.5 / 内壁面 -89.5 / 板边 -88 / 座口 -88.23,
   **从外壁面到座口有 3.27mm 死区**。Type-C 完全插入时塑料头前端面基本贴住座口,
   所以这 3.27mm 得由塑料头自己穿过去 —— 开口小于塑料头, 插头就顶在外壁上,
   金属壳只能进 6.5 - 3.27 = 3.2mm, 大约一半, 根本接触不上。
   原来 USB_W=10 / USB_H=5 是照金属壳 (8.34 x 2.56) 开的, 塑料头过不去。
   ⚠ 机械约束 §287 曾写"穿 2mm 壁 + 1.7mm 间隙仍插得到底"—— 那句话的算术不成立,
     它只比了"插头长度 > 死区", 漏了塑料头也得跟着进去。
   用户实测线材塑料头 **11 x 6.5**, 四周各留 0.75 余量 -> 12.5 x 8.0。   */
USB_W = 12.5;  USB_H = 8.0;  USB_Z = 8.5;  USB_Y = -6;

/* 拨柄开口。拨柄尖 -93.51, 外壁面 -91.5 -> 露出 **2.01mm**。
   ⚠ 判据是尺寸基准 §366 定的"外壁面再露 1mm 手指才拨得动"。
     SW3 原在 x=-82.6 时拨柄尖 -92.01, 只露 0.51mm, **不达标** ——
     那张 H 选型表是按老底座(外壁面 -75/板边 -71)算的, 底座放大到 183 后没人回头重算。
     因为物料已买齐(H=7 换不了), 改成把 SW3 在 PCB 上往 -X 挪 1.5mm 补回来。 */
PSW_W = 8;   PSW_H = 4;  PSW_Y = 17;

// 上盖 TP4056 充电指示灯观察孔。U3 在 (-74.8, -6), 本体 28×17 占 x -88.23..-60.23,
// y -14.5..2.5。窗 10(x) × 6(y) -> 占 x -85..-75, y -3..3。
// ✅ LED 位置**用户按实物给定 (-80, 0)**, 不再是"紧邻 Type-C 座"的猜测值 (原 -84,-6)。
// ⚠ 该窗口会在 -X 端局部切断止口环 (环占 |x| 82.75..89.25), 只影响定位不影响强度;
//   挪到 -80 之后切掉的从 6.25mm 减到 **2.25mm**, 比原来还轻。
LED_WIN_POS = [-80, 0];
LED_WIN_L   = 10;     // x 向
LED_WIN_W   = 6;      // y 向

/* --- v2.4 排布翻转 --------------------------------------------------
   v2.3 之前: 电池占 -X, 四个模块散放 +X。两个硬伤——
     a) 前端面的 Type-C / 总开关开口后面坐着电池, 而 TP4056 在 x=+57,
        离开口 132mm, 接口对不上;
     b) 两个按键(x=-50/-30)正压在电池顶上, 电池顶 12mm、上盖背面 15mm,
        中间只剩 3mm, 放不下 6×6 轻触开关。
   加上底板选型已锁定为**单块承载底板**(U1 DevKit 插板上, 模块全部上板),
   老的"每个模块四根限位柱"架构已经作废。
   现在按"接口在哪、板子就在哪"翻过来: 承载底板占 -X 半场正对前端面开口,
   电池挪到 +X 半场。按键位置不动, 自然落到底板上方。                    */

// 电池 103450 卧放。⚠ 用**含保护板和引线的成品尺寸 51×34×10**(卖家确认),
// 不是裸电芯的 50。仓比成品每边放 1mm -> 53.5 长 × 36 宽。
// 引线必须朝 -X (承载底板那侧), 从 -X 挡边上方 (z 12..22 的空隙) 跨过去接 J4。
BAT_L = 51;  BAT_W = 34;  BAT_T = 10;
BAT_X0 = 36;  BAT_X1 = 89.5;  // 电池仓 x 范围 (53.5), +X 端直接靠内壁
BAT_YH = 18;                  // 电池仓 y 半宽 (36)

// 承载底板 (工程"道闸玩具承载底板")。**外形与安装孔是 PCB 定稿值**,
// 见 道闸玩具_底板机械约束_v1.md §七之二 —— 结构让路给 PCB, 不是反过来。
PCB_X0    = -88;  PCB_X1 = 32;   // 120 长
PCB_YH    = 32.5;                // ±32.5 -> 65 宽
PCB_T     = 1.6;
PCB_SO    = 2.0;                 // 支撑柱净高 -> 板底 z=4, 板面 z=5.6
/* 🔴 -X 两角是 **45° 倒角**, 不是方形缺口。
   2026-08-15 从 EDA 读回真实板框才发现 CAD 一直建成方缺口 ——
   方缺口挖掉的料**更多**, 所以自检一直显示"没问题", **CAD 在偏乐观的方向错了**。
   按真实倒角算: 角螺柱中心 (-87,32) 到倒角斜边只有 2.47mm, 而螺柱半径 3.0
   -> 板子啃进螺柱 0.53mm, 装不进去。
   倒角要 ≥6.2 才让得开, 取 7 -> 净距 0.89mm。已确认新增挖除区内没有任何铜。 */
PCB_CHAMFER = 7;
PCB_MNT   = [[-82, 27], [-82, -27], [26, 27], [26, -27]];
PCB_Z     = WALL + PCB_SO + PCB_T;   // 板面 z = 5.6
// 板面以上可用高度 = TRAY_H - 5.6 = 16.4mm (中央区); 见机械约束 §三
// PCB_SO 不要往上加: 它每加 1mm, 板面以上就少 1mm
// U1 叠高 = 排母 + DevKit 排针隔片 2.5 + PCB 1.57 + 模组 3.1
//   标准 8.5 排母 -> 15.67  ✗ ; 低背 5.0 排母 -> 12.17  ✓  <- 采用这个
U1_STACK  = 12.2;

/* ============ 按键帽 btn_cap (v3.0 新增打印件 ×2) ============
   6×6×12 的轻触开关顶杆只到 z=17.6, 盖面在 25 —— 差 7.4mm, 够不到;
   而且顶杆是 φ3 的小锥台, 6~10 岁的手指按着硌手。所以配打印帽:
   按压面 φ8.5、露出盖面 5mm、法兰 φ12 卡在背面沉孔里防脱。
   ⚠ 帽子是**扣上盖之前从背面放进沉孔的**(法兰比通孔大), 装配顺序别搞反。
   晃动量取决于配合间隙: FDM 0.5 -> 帽顶晃约 1mm; 树脂 0.3 -> 约 0.6mm。
   建议和转毂一起用树脂打, 把 CAP_CLR 调到 0.3。                          */
CAP_CLR      = 0.5;   // 直径上的配合间隙
CAP_EXPOSE   = 5.0;   // 露出盖面的高度
CAP_FLOAT    = 0.2;   // 帽底与顶杆之间留的浮动, 免得静止时就预压住开关
CAP_BLIND_D  = 3.2;   // 套住顶杆的盲孔 (顶杆 φ3->φ2.5 锥台, 松套即可)
CAP_BLIND_L  = 1.0;
// 法兰厚。**这个数直接决定按键按不按得动**:
//   帽子能下压的距离 = 沉孔总深 4.0 − 法兰厚
//   而按下去要走 CAP_FLOAT(0.2 空行程) + 开关行程 0.25 = 0.45
//   取 3.5 的话只剩 0.5 可压, 余量 0.05mm —— 打印公差 ±0.15 就能让法兰先坐死
//   在沉孔底上, 开关根本压不到。取 3.0, 余量 1.0−0.45 = 0.55mm。
//   (导向不受影响: 法兰 3.0 + 柄在通孔里 1.5, 跨距仍有 4.5mm)
CAP_FLANGE_T = 3.0;
CAP_LOW_D    = 8.0;   // 法兰以下那段柄 (悬在腔里, 不受孔约束)
// 绝对高度链 (z=0 = 底座底面外表面)
CAP_SEAT_Z   = TRAY_H + BTN_CB_T;                        // 23.5 沉孔顶面 = 法兰止位
CAP_POCKET_Z = CAP_SEAT_Z - BTN_CB_T - BTN_GUIDE_H;      // 19.5 沉孔下口
CAP_TOP_Z    = BASE_H + CAP_EXPOSE;                      // 30.0
CAP_BOT_Z    = PCB_Z + BTN_SW_H + CAP_FLOAT - CAP_BLIND_L;  // 16.8
CAP_H        = CAP_TOP_Z - CAP_BOT_Z;                    // 13.2
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

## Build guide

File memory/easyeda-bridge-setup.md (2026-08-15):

---
name: easyeda-bridge-setup
description: 用 Claude Code 直接操作嘉立创EDA专业版的桥接环境（已在本机跑通）
metadata: 
  node_type: memory
  type: reference
  originSessionId: 71e9ee68-c3ea-425e-adaf-0b0540f0699e
  modified: 2026-08-11T13:13:52.291Z
---

可以用 Claude Code 程序化操作嘉立创EDA（EasyEDA）专业版，链路已在本机验证通过：

```
Claude Code → HTTP 127.0.0.1:49620 → Bridge Server → WebSocket → Run API Gateway 扩展 → EDA
```

三个组成部分：
1. **EDA 侧扩展** `run-api-gateway.eext`（本机 v1.0.5，已装）。它**不监听端口**，是扫描 49620-49629 主动连出去的一端。装完必须在 EDA「高级 → 扩展管理器 → 已安装」里勾选 **「外部交互 External Interactions」**，否则不会去连。
2. **Bridge Server**：`easyeda-api` Skill 自带，装在 `C:\Users\Administrator\.claude\skills\easyeda-api`（来自 github.com/easyeda/easyeda-api-skill）。启动：`cd 该目录; node scripts/bridge-server.mjs`。需 Node 22+（本机 v22.17.0）。仅监听 127.0.0.1。
3. **调用方式**：
   - `GET http://127.0.0.1:49620/health` → 看 `edaConnected`
   - `POST /execute`，body `{"code":"return await eda.dmt_Project.getCurrentProjectInfo();"}`
   - PowerShell 调用要用 `[Text.Encoding]::UTF8.GetBytes($body)` 传 body，否则中文会乱码

API 参考文档在该 Skill 的 `references/`（120+ 类）、`guide/`、`user-guide/` 目录里。

**实测踩过的坑**（2026-08-11 验证）：
- `dmt_Project.createProject()` **不要传 teamUuid**。传 Personal 团队的 uuid 会返回 undefined，不传反而成功。
- 工程创建时会自动带一个 Board1+schematic1，**不要再调 `createBoard()`**，否则多出 Board2。`deleteBoard()` 会导致 EDA 重载、桥短暂断开（会自动重连，windowId 变化）。
- `createSchematic(boardName?)` 的参数是**板子名**不是原理图名。
- `lib_Device.search` 完整签名有 **6 个参数** `(key, libraryUuid?, classification?, symbolType?, itemsOfPage?, page?)`，但 `_quick-reference.md` 里只列了 5 个（漏了 symbolType）。按 5 个传会全部搜到 0 条。**必须读 `references/classes/` 里的完整文档，不能信快速索引。**
- 原理图坐标单位 **0.01 inch**。引脚 `getState_X/Y` 返回的是**引脚外端的连接点**（可直接作为导线端点）。
- `sch_PrimitiveWire.create(line,...)` 的 line 是**分段数组**，每个子数组是一整段的连续坐标 `[x1,y1,x2,y2,...]`。写成 `[[x1,y1],[x2,y2]]` 会因"每段只有一个点"而失败。**斜线段非法，只能水平/垂直。**
- ⚠️ **`sch_Netlist.getNetlist()` 会挂起**（三种 type 都 >30s 超时，超过桥的 30s 上限）。

**2026-08-13 补充的坑（都会静默给错结果）：**

- 🔴 **导线的 `getState_Net()` 已经全部返回空字符串**，`getAll("GND")` 也返回 0 条（2026-08-11 时还能用）。**网络名只存在于网络端口符号上**，连接关系只能靠坐标几何重建：每根导线的全部顶点并为一个连通块 → 把落在任意线段上的引脚点并进去（含 T 型接点）→ 连通块内的端口符号给出网络名。同名的多个连通块是同一条逻辑网络（星型接法）。
- **校验工具必须先复现已知基准、且必须带阳性对照**（故意挪开一个引脚坐标，确认它掉出网络）。否则工具坏了都不知道。
- **执行上下文里没有枚举对象**，`EPCB_*` 一律 undefined，只能传字面值；而**字面值和成员名对不上**：`RECTANGLE→"RECT"`、`OBLONG→"OVAL"`、`REGULAR_POLYGON→"NGON"`。必须去 `references/enums/` 查反引号里的实际值。
- **`"ELLIPSE"` 画不出椭圆**：`["ELLIPSE",86.6,70.9]` 被静默压成 70.9×70.9 正圆。长短轴不等要用 `"OVAL"`。只有回读焊盘尺寸才发现。
- **系统库封装无法 `openInEditor`**（返回 `false`，随后 PCB 接口因当前文档仍是原理图而抛 `Cannot read properties of null (reading 'map')`）。要看/改系统库封装，先 `lib_Footprint.copy` 到**个人库**（`getPersonalLibraryUuid()`）；目标库传 `getProjectLibraryUuid()` 返回的 `"project"` 会失败。
- **换器件只能删了重建**：`sch_PrimitiveComponent.modify()` 改不了 symbol/footprint/device，属性表里根本没有这几项。重建后 `create()` 返回的对象是旧快照，`designator` 要另外 `modify()` 再 `get()` 回读确认。
- **`lib_Device.create(lib, name, cls, association, ...)`** 的 `association` 可以直接引用**系统库的符号 + 个人库的封装**，所以自建器件时符号可以借现成的，不必画。
- 🔴 **符号 uuid 有两套，靠长度区分**：`association.symbol.uuid` 必须是**库里的 32 位 uuid**（来源：`lib_Device.search()` 结果的 `symbolUuid` 字段）。原理图元件 `getState_Symbol().uuid` 返回的是**文档局部 id，只有 16 位**，传进去 `create` 必抛错，而错误序列化出来只有 `[object Object]`，完全看不出原因。**32 位=库 uuid，16 位=文档局部 id。** `getState_Component()` / `getState_Footprint()` 的 uuid 同理。
- **破坏性脚本要把"新建"排在"删除"之前**。上面那个 create 失败时删除还没执行，原理图毫发无伤；反过来写就会删完才发现建不出来。
- **`pcb_Document.importChanges()` 是异步的**：返回 `true` 后元件不会立刻出现，要另起一次调用再查。而且它**按位号匹配已有元件、不会换封装**——改了封装要先把 PCB 里那个元件删掉再导入；整批重来最保险（板框和焊盘图元不受影响）。导入同样可能弹确认框。
- **`getPrimitivesBBox()` 把位号文字算进去**，不能当实体尺寸用（自画 18.1 宽的丝印，包围盒报 21.08）。要实体尺寸就用封装文档里的实测值。
- **元件间距不能只比单轴**：两个盒子 X、Y 都不重叠时是对角相邻，真实间距是对角线长度，只看 X 会把 13mm 误报成 0.34mm。
- `lib_Footprint.modify` / `lib_Device.modify` 的 `classification` **传 `null` 会抛** `Cannot destructure property 'primaryClassificationUuid'`，要传 `undefined`。
- 层 id：`TOP=1` `BOTTOM=2` `TOP_SILKSCREEN=3` `BOARD_OUTLINE=11` `MULTI=12`（THT 焊盘用 12）。非金属化孔靠 `metallization=false`，没有专门的 padType。
- 🔴 **API 调用会被 EDA 的模态对话框卡住 → 表现为"超时 30000ms"，不是 bug。** `sch_PrimitiveComponent.create` 在库版本比工程库新时会弹「发现这个器件有更新，是否先更新掉工程库里的这个器件？」，一直等到用户点按钮。**连续超时时先让用户看一眼 EDA 界面有没有弹窗**，别去猜 API 坏了。
- **工程库会存一份封装/符号的副本，改个人库的原件不自动传导。** 副本的 uuid 是 16 位。点了「更新」之后：器件名会刷新（连已放置的元件也跟着变），但**封装副本的名字仍是旧的**；副本 `openInEditor` 打不开（`"project"` 和 `undefined` 都抛错），**几何无法用 API 查证**。要核实只能等落到 PCB 文档里再读。
- 建封装时**不要重编焊盘号**，只把编号 N 的焊盘搬到目标位置 N，避免瞬时编号冲突。
- 保存：原理图 `sch_Document.save()`，封装编辑器（documentType 4）用 `pcb_Document.save()`。

**2026-08-15 新增的坑（建遥控器工程时踩的）：**

- 🔴 **网络标识（GND / 5V 这类 netflag 符号）放不进去**：`sch_PrimitiveComponent.create({libraryType:"2",...})` 放 `symbolType=18` 的符号**必定卡满 30 秒超时**（其余调用同时都正常，`1+1` 秒回）。推断是 EDA 弹了网络命名框在等点击。**绕法：重排版面让每条网络都能用普通导线连通且零交叉**，不依赖标识。
- **找 netflag 要按符号类型过滤**：`lib_Symbol.search(key, undefined, undefined, 18, n, 1)`，`ELIB_SymbolType.NET_FLAG=18`、`NET_PORT=19`，**而且要传数字 18 不是字符串 "18"**（传字符串报 `Cannot read properties of undefined (reading 'facets')`）。不过滤的话搜 "VCC" 全是无关元件。GND=`029dc91398624049926195124347581a`、Power-5V=`8a04e22374494d55957a030ec33de1cb`，库 `0819f05c4eef4c71ace90d822a990e87`。
- 🔴 **桥的 30 秒上限是按"一次 /execute"算的**，不是单个 API。一次塞十几个调用（尤其 `lib_Device.search`，很慢）就会整批超时、**前面已执行的部分却已经生效**。要么拆批，要么**跳过搜索直接构造 `{libraryType:"2", libraryUuid, uuid}`**。
- **新建工程不会自动切过去**：`createProject` 返回的是 **uuid 字符串**（不是对象），且当前工程不变；要 `dmt_Project.openProject(uuid)`。列工程用 `getAllProjectsUuid(teamUuid)`，**不传 teamUuid 返回 0 条**。
- 🔴 **新工程刚打开时没有任何文档处于激活状态**，此时调 `sch_PrimitiveComponent.create` 会**卡 30 秒超时**（症状与弹窗一模一样，容易误判）。先 `dmt_EditorControl.openDocument(原理图页 uuid)`，用 `dmt_Schematic.getCurrentSchematicInfo()` 确认不是 "none" 再动手。
- **`sch_PrimitivePin.getAll()` 恒返回 0 条**，引脚要从元件对象上取：`(await comp.getAllPins())`。
- **`getState_Line()` 读回的是按段展开的扁平数组**（每 4 个数一段 `x1,y1,x2,y2`），与 `create()` 传入的"分段数组"格式不同。写进去一条 3 折的折线，读回来是 3 段。
- `sch_Net.getAllNetsName()` 同样返回**空**——不只是导线的 `getState_Net()`。
- `lib_Footprint.get` / `lib_Footprint.copy` 对**系统库**封装都抛 `[object Object]`，几何读不出来。要核封装尺寸只能等元件落到 PCB 文档里再读焊盘坐标。

**2026-08-15 做遥控器 PCB 时新踩的：**

- 🔴 **`pcb_MathPolygon.createPolygon` 不会自动闭合**，尽管文档明写"如果首尾不重合将会自动重合"。画板框少了最后一条边，**API 全程报成功、`zoomToBoardOutline()` 也返回 true**，是用户看图才发现的。**必须显式把首点补回末尾。**
- **`createPolygon` 只做闭合形状，不能画走线**：传开放路径直接抛"无法创建多边形图元"。走线用 `pcb_PrimitiveLine.create(net, layer, x1,y1,x2,y2, width)` 一段一段建。板框/挖槽用 `pcb_PrimitivePolyline.create(net, 11, polygon, width)`。
- **`importChanges()` 会弹确认框**：返回 `true` 但 PCB 上元件数始终是 0，而且**其余 API 全程正常响应**（不像放 netflag 那样卡超时），极易误判成"API 坏了"。要让用户去 EDA 点一下。
- **PCB 坐标单位是 mil**（原理图是 0.01 inch）。`mm = mil × 0.0254`。
- **系统库封装的几何只能落到 PCB 里才读得到**：`comp.getAllPins()` 拿相对元件中心的焊盘坐标，反算行距/跨距。`lib_Footprint.get`/`.copy` 在库里一律抛不透明错。
- **旋转 180° 会让对称封装的引脚编号对调**（SK-12D07VG7 的 1/3 脚）。改朝向之后**必须重布**碰到它的网络，光转不管走线会静默断开。
- 🔴 **`pcb_Drc.check()` 不传参返回的那个布尔值不可信，别拿它下结论。** 之前记的是"不传参返回 false"，但 2026-08-15 改完遥控器板框后同样不传参却返回 **`true`** —— 同一块板、同一个 API，两次相反。这个布尔到底编码"跑没跑成"还是"有没有错"没搞清楚，**当"零错误"的证据用就是在给自己发假通过**。一律用 `check(true, false, true)`，它返回**错误对象数组**，`length === 0` 才是干净。
- **连通性判据要用阳性对照标定**：取 0.02mm 时误报了一条真连通的网络（走线端点距焊盘中心 0.01mm），放到 0.03mm 才对。**太严造假故障、太松放过真断线**，必须用"偏移 0.1/0.3/2.0mm 都必须判断开"来标定。
- 🔴 **连通性校验必须分层**。不看层的版本把底层走线从顶层 SMD 焊盘底下穿过也算连上，**给了假通过**，是 DRC 抓到的。正确模型：节点 =（x, y, 层），同层线段连两端，**只有直插焊盘（层 12）和过孔跨层**。
- 🔴 **删走线只删 `pcb_PrimitiveLine` 会留下孤儿过孔**，重布后 DRC 报 `Connection Error` 指着不在任何走线上的过孔。删线必须**连 `pcb_PrimitiveVia` 一起清**。
- 🔴 **算板边净距必须按焊盘"铜箔边缘"，不能按中心。** 用中心距 0.45mm 当判据选出来的螺柱缺口位置，DRC 直接报 `Board Outline to TH Pad` —— THT 焊盘半径约 0.9mm，0.87mm 的中心距实际净距是 0。判据要 **中心距 ≥1.5mm**。同一类错误在这个项目里犯过三次（元件间距只比单轴、包围盒含位号文字、这次的焊盘中心）。
- **改板框之后必须重跑 DRC**：自动布线器会把板边当走线通道用（它布线时看到的是光板），后加缺口就会撞上已有走线。
- **旋转 180° 前先想清楚引脚会不会镜像到另一排**：C3 SuperMini 转 rot 90→270 之后，用到的 5 个焊盘从 y=+2.12 全部跑到 y=−13.12，碰到它的 5 条网络必须整体重布。

**2026-08-15 板框倒 R2 时新踩的：**

- 🔴 **`dmt_Project.openProject()` 换不了工程，恒返回 `false`**（`openProject(uuid)`、`openProject(uuid, true)`、把工程 uuid 喂给 `openDocument` 三种都试过）。不是权限问题——`getProjectInfo(uuid)` 能跨工程读到信息。**跨工程只能让用户手点开**，而且 `dmt_Pcb.getAllPcbsInfo()` 只列当前工程，所以也拿不到别的工程的文档 uuid 来绕。**同工程内换文档正常**：`dmt_EditorControl.openDocument(docUuid)` 返回 `docUuid@projectUuid`。
- **想知道 EDA 里现在开着哪些标签**：`dmt_EditorControl.getSplitScreenTree()` 返回 `{id, tabs:[{tabId, title, data:{doctype}}]}`，`tabId` 就是 `docUuid@projectUuid`。（`getTabsBySplitScreenId()` 我没喂对参数，返回空，直接读 tree 更省事。）
- **板框不是 Region 也不是 Line，是 `pcb_PrimitivePolyline`（层 11）**。`pcb_PrimitiveRegion.getAll()` 对板框返回**空数组**，`pcb_PrimitiveLine.getAll()` 只给铜层走线。顶点在 `poly.polygon.polygon`，是**扁平数组**且夹着模式记号：`[x0,y0,"L",x1,y1,x2,y2,...]`，单位 mil。解析时遇到字符串要跳过。
- **改板框不用删了重建**：`pcb_PrimitivePolyline.modify(id, {polygon})` 原地改，图元 ID 不变（删重建还得担心孤儿过孔）。
- ⚠ **多边形数组支持 `ARC` 段，但文档自相矛盾**：正文写 `startX startY ARC angle endX endY`，示例却是 `[..., "ARC", 400, 220, 15, ...]`（角度在末位）。**这个 API 已经在"自动闭合"上骗过一次，别赌**——倒圆角改成 16 段离散化，最大偏差 0.0024mm，比铣边公差 ±0.2mm 低两个数量级。
- 🔴 **回读校验的容差不能设到 1e-6mm**：EDA 把坐标量化到 mil，回读的 −28.5 是 −28.49999888，**偏差约 1.7 nm**。我第一遍用 1e-6 当判据，23 个完全正确的顶点被报成"偏离几何"，差点当成真故障去改。**容差取 1e-3mm 量级**（仍比任何制造公差严三个数量级）。
- **验板框要带阳性对照**：光确认"新圆弧点都在 R=2 上"不够，还要确认**原来那四个直角点已经查无此点**——不然可能是在旧轮廓上又叠了一圈新点。

**2026-08-15 改主机 PCB（挪 SW3 + 让开安装孔）时踩的：**

- **`pcb_PrimitiveLine.modify()` 改端点会"自动分段"**，不是把端点搬过去。把一段 `(-82.6,17)->(-80,17)` 的起点改成 `-84.1`，读回来变成**两段** `(-84.1,17)->(-82.6,17)` + `(-82.6,17)->(-80,17)`。电气上连通、DRC 也过，但**几何比对时按"一段"去找会找不到**。改完一律重建连通性再判断，别拿段数或坐标逐条比。
- **改了走线必须 `rebuildCopperRegion()`**，否则 DRC 报 `Copper Region(Filled) to Track`。覆铜是改板框时要重建，改走线**同样**要重建。
- **覆铜范围读 `pcb_PrimitivePour.getAll()` 的 `complexPolygon`，别读 `pcb_PrimitivePoured` 的 `pourFills`**。前者是用户画的区域，常常就是一句矩形模式 `["R", x, y, w, h, rot, round]`（x/y 是**左上角**），简单可靠；后者是实际填充几何，**坐标系我没搞明白**——解析出来的包围盒只有 11.5×5.8mm 而板子是 120×65，自己的合理性检查就没过。**解析完必须拿包围盒对一下板子大小**，对不上就说明解错了，别拿错的数下结论。
- **`pourFills[].path.complexPolygon` 里的 `ARC` 是 `"ARC", 角度, endX, endY`** —— 和格式文档正文一致、和文档示例 `["ARC",400,220,15]` 不一致。**示例是错的。**
- **阳性对照的偏移方向要挑，不能只偏 X。** 校验连通性时把焊盘沿 +X 偏 2mm，`VBAT_PROT` 居然还"连通"——因为那根走线本身就是水平的，焊盘**顺着自己的线滑**了，从没离开导体。**轴对齐的走线要用斜向偏移**（x、y 同时偏）才证明得了判据有效。这条不是校验器的 bug，是对照本身设计错了。
- **GND 这类覆铜网络会被"走线连通性"判成断开**，因为它靠覆铜不靠走线（主机 GND 有 22 个焊盘、0 根走线）。**校验时要显式排除覆铜网络**，否则每次都报一条假故障，报久了就没人看了。

**核心纪律**：元件放了、线画了、**API 也报成功**，网表仍可能是错的（历史上 82 根线静默只生成 78 根；这次板框少一条边也是 API 全绿）。必须坐标比对逐条校验，不能靠看图，也不能信返回值。
**阳性对照要放一个"差一点点"的**：遥控器那次用了个距真引脚仅 5 个单位的假引脚，确认它掉出网络——只放个远处的假点，证明不了工具在判别距离。相关项目见 [[daozha-toy-scope]]。

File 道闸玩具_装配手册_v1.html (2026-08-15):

道闸玩具 · 6~10 岁

# 装配手册

从裸板、元件、打印件和螺丝，到一台会听话起落杆的道闸。本次不走 SMT 贴片，全部手焊。 按阶段走，红色「顺序卡点」的地方不能跳——那几步做反了要拆回去，个别会烧板子。

对应 CAD v3.3 · 主机 PCB1 · 遥控 PCB1 打印件 12 种 14 件 螺丝 27 颗 贴片件 9 颗（手焊） 预计 4~5 小时（不含打印）

阶段 0

## 开工前

工具、耗材、以及三条贯穿全程的规矩。

贯穿全程的三条规矩

1 · 插拔任何东西之前，先把拨动开关关掉。 主机和遥控器都一样。开关串在电池和模块的 5V 脚之间，关掉就是物理断开——这是唯一能防止 5V 倒灌回 TP4056 的 OUT+（它与 B+ 直连，保护只切负极）把电芯怼坏的办法。

2 · 塑件里的自攻螺丝，一律手拧，不用电动批。 底孔是 φ1.7，靠挤压塑料成型；电动批一冲就把孔撕开，再也咬不住。转毂那颗横穿螺丝尤其不能用。

3 · 底孔不要扩孔。 拧起来发紧是正常的。扩到 φ2 以上就彻底没有咬合力了。

下单时别勾 SMT 贴片

本次只买裸板，元件自己买、自己焊。两块板一共只有 9 颗贴片件（主机 8、遥控 1），付贴片费不划算，但意味着工具和顺序都要按手焊来。

0603 一定要多买。 手焊时会飞、会烧、会掉进键盘缝——每种至少备 10 颗，一盘也就几块钱。

### 工具

- 电烙铁（可调温，设 350 ℃）+ 尖头或小刀头烙铁头
- 0.6mm 细焊锡（0603 用 1.0mm 的锡会一下子给太多）
- 助焊剂（免洗液态或松香膏）——手焊贴片没有它基本焊不好
- 弯头镊子（夹 0603 用，直头不好按）
- 放大镜或头戴放大镜（查桥接，0603 靠肉眼看不清）
- 吸锡带（清桥接，别拿烙铁硬刮）
- 十字螺丝刀 PH0（M2 自攻用）
- 长杆细螺丝刀——要能穿过闸体前面板 φ3 的孔去拧凸轮顶丝，杆径 < 2.5mm、长 > 40mm
- 万用表（调升压、查通断）
- 卡尺（核对模块实测尺寸）
- 剥线钳 + 细软导线（闸体到底板的飞线，建议 26~28 AWG 硅胶线）

### 耗材

- 螺纹胶（凸轮顶丝必须点，它是转毂唯一的轴向固定）
- 502 或热熔胶（配重螺母、飞线固定、闸杆 A/B 对接双保险）
- EVA 泡棉（主机电池压紧，电池顶到上盖有 7mm 空隙）
- 2 kΩ 贴片电阻（换 TP4056 的 Rprog，见阶段 1 第 2 步）

焊盘是 OSP 工艺

OSP 保质期约 6 个月，受潮更短。板子到手尽快焊，暂时不焊就留在原包装袋里配干燥剂。

两块板都是两面 GND 覆铜，接 GND 的直插焊盘吃热多，OSP 又比喷锡难润湿——烙铁给足温度和助焊剂，看到锡明显爬满孔壁再撤，否则容易出看着焊上了其实是虚焊。

阶段 1

## 主机 · 电子装配

承载底板 120 × 65。全部焊完再进机械装配，板子装进托盘后就够不到背面了。

1

### 先焊贴片件——两块板一共 9 颗

顺序卡点 · 必须在所有直插件之前

本次不走嘉立创 SMT 贴片，全部手焊。贴片件一定要最先焊——排母、端子、电解电容一上板，板面就再也放不下镊子和烙铁头了，0603 更是彻底够不着。

板 | 位号 | 值 | 封装 | 注意
主机 | C2 C4 C5 | 100nF 50V X7R | 0603 | 无极性
主机 | R3 R4 | 100 kΩ ±1% | 0603 | 电池采样分压
主机 | R5 | 1 kΩ ±1% | 0603 | 蜂鸣器基极限流
主机 | D1 | 1N5819 肖特基 | SMA | 有极性
主机 | Q1 | S8050 NPN | SOT-23-3 | 有方向
遥控 | C1 | 10 µF | 0805 | 无极性

#### 0603 / 0805 的手焊手法

1. 在一个焊盘上先镀一点锡（另一个保持干净）
2. 镊子夹住元件按在位置上
3. 烙铁碰那个镀了锡的焊盘，锡一熔就把元件吸住——先别管焊得好不好，能定位就行
4. 焊另一端，这一端要焊到位
5. 回头补第一端：第一次那点锡是旧的、也没加助焊剂，必须重熔一次

最容易出的问题：立碑

0603 常常一端接 GND 覆铜、另一端接信号。两端升温速度差很多——GND 那端热量被大铜面抽走，信号端先熔，表面张力一拉就把元件竖起来（立碑）。

所以第一步的「镀锡那一端」要选不接 GND 的那端，最后再攻 GND 端并且多停 1~2 秒。

极性与方向

D1（SMA）：丝印上那道白杠是负极／阴极，对准元件本体上有色环的那头。装反了升压后级直接短。

Q1（SOT-23-3）：三个脚不对称，按丝印外框的方向放，别只看引脚数对得上。

温度 350 ℃，不要超过 380。 0603 的陶瓷体耐热有限，靠调高温度去攻 GND 大铜面是错的做法——宁可烙铁多停 1~2 秒，或者换个更大的烙铁头把热量喂上去。

焊完逐颗查

放大镜扫一遍有没有桥接（尤其 SOT-23 三个脚之间），万用表蜂鸣档量相邻焊盘不导通。有桥接就用吸锡带蘸助焊剂拖一下，别拿烙铁硬刮。

2

### 先把 TP4056 的 Rprog 换成 2 kΩ

模块出厂是 1.2 kΩ = 1000 mA。换 2 kΩ → 600 mA。

理由不是电池受不了，是发热：1 A 充电时模块自身耗散 1.2 W 以上，外壳会烫手，而且 TP4056 的热调节会自己降流，充电变慢且不可预测。600 mA 过夜充满绰绰有余。

趁模块还没焊上板

这颗电阻在模块正面，焊到底板上之后周围就挤了，先换掉省事。

3

### 焊直插件：先矮后高

顺序：电阻电容 → 排母 → 端子 → 开关 → 蜂鸣器。矮的先焊，板子才能平放在桌上不翘。

排母必须是低背 5.0mm

常见的 8.5mm 排母会让 DevKit 叠高到 15.67mm，而板面以上净空只有 13.4mm——装不进去，上盖扣不上。低背 5.0 叠高 12.17mm，余 1.2mm。

焊排母之前先把 DevKit 插上去比一下，保证两排平行不歪；歪了模块插拔会别劲。

4

### 焊 U3 TP4056 与 U4 MT3608（贴板直焊，不用排母）

U3 的 Type-C 那端朝 −X，本体前沿与板边基本齐平（悬出 0.23mm）。

焊 U3 之前，拿充电线试插一次

外壁面到 Type-C 座口有 3.27mm 死区，靠插头的塑料头穿过去。外壳开口已按实测塑料头 11 × 6.5 放大到 12.5 × 8.0。

换更粗的线就要重新量、重新改开口再打印。焊死之后才发现插不到底，就得拆模块。

U2 DRV8833 的焊盘是按列编号（1–8 左列 / 9–16 右列），不是常规奇偶交替——照编号连会全错，接线前对一遍选型锁定文档里的对照表。

5

### 调升压 MT3608 输出到 5.0 V

顺序卡点 · 必须在插 DevKit 之前

MT3608 出厂电位器是随机位置，可能输出十几伏。先接电池、用万用表量着把它调到 5.0 V，确认稳定，再插 DevKit。

反过来做，第一次上电就可能把 ESP32-S3 模块烧掉。这一步不可逆。

- 拨动开关打开 → 万用表接 MT3608 输出
- 慢慢转电位器到 5.00 V
- 关掉开关，等 10 秒，再开一次确认还是 5.0 V

6

### 插上 U1 DevKit 和 U2 DRV8833

确认拨动开关是关的再插。模块靠排母架空，插到底但别硬压。

阶段检验

开关打开 → DevKit 上电指示灯亮 → 用万用表确认 3V3 和 +5V 都正常 → 关掉开关。此时先不要装进外壳。

阶段 2

## 主机 · 闸体子装配

闸体是独立的子装配，全部在左壳里做完再合右壳。这是全机最容易装错的部分——转毂有一条唯一可行的装配路径。

7

### 左壳装两只微动开关——先松着拧

M2×10 盘头自攻 × 4，从腔内往两块安装台上拧。

现在别拧紧

底孔是径向长圆孔（±1.5mm 可调），就是为了后面对着凸轮微调位置用的。现在拧到「能转动但不松垮」就停。

长圆孔里自攻螺丝只咬两条长边，咬合面积少一半——最终拧紧时手感发紧就停，别使劲。

8

### 把 N20 电机推进隧道

减速箱端面朝里（朝转毂那侧），沿隧道推到尾端顶住尾挡筋。

推起来发紧是设计成这样的

隧道侧壁有两道压筋，单边过盈 0.15mm，推进去时会被电机蹭平——这正是靠它吃掉配合间隙的。

没有压筋的话电机能在方孔里转 3.94°，折到 300mm 杆尖就是 20.6mm 的旷量，起落换向时肉眼可见。

要用点力但不该「推不动」。真推不动先检查隧道里有没有打印残留的支撑或毛刺。

9

### 转毂穿过壁孔 → 从腔内套上凸轮

顺序卡点 · 凸轮不能先装

闸体壁上的轴颈孔只有 φ8.5，而凸轮盘是 φ18.6——装好凸轮的转毂物理上穿不过去。转毂拆成两件就是为了这个。

正确顺序：① 转毂从壳外沿轴向推进壁孔 → ② 手伸进腔内，把凸轮套到轴颈上。

凸轮的 D 形孔配轴颈上的键面，只有一个方向能套进去，套进去角度就是对的，不需要装配时对相位。

10

### 拧凸轮顶丝并点螺纹胶

把闸杆（或转毂夹臂）摆到落杆位 0°，此时顶丝正对闸体前面板的 φ3 进入孔。用长杆细螺丝刀从壳外捅进去拧 M2×8 盘头自攻。

必须点螺纹胶

这颗顶丝是转毂唯一的轴向固定：拧紧后往外拔会被 φ12 轴承凸台挡住，往里推会被夹杆臂撞外壁。它一松，整个转毂加闸杆就会往外滑出来。

顶丝是径向的，而闸体开口在分模面方向，合壳之后伸手够不着——所以才专门开了那个 φ3 孔。

11

### 调两只微动开关的位置，然后拧紧

手动慢慢转动转毂，观察凸轮和开关簧片杠杆：

- 转到落杆位时，凸起应刚好把杠杆压下（听到咔哒）
- 转到中间（约 45°）时，杠杆应已经释放
- 转到起杆位时，另一只刚好压下

沿长圆孔前后滑动开关直到三条都满足，再拧紧。

阶段检验

反复手动扫 0°↔90° 三次，两只开关都应在正确位置干脆地通断，中间行程完全释放。

12

### 装麦克风，焊飞线

INMP441 圆板（φ14 × 厚 1）放进闸体前面板内侧的圆窝，压舌卡住。

焊 5 根飞线下来：SCK / WS / SD / VDD / GND（L-R 就近接 GND）。线留足够长，要一直走到底座里的 J3 端子。

13

### 合右壳，四颗长螺丝对拧

M2×30 沉头自攻 × 4，从右壳外表面往左壳螺柱拧。

这四颗最容易顶裂导向柱

M2×30 又细又长，要跨过 23mm 才够到对面螺柱。先用手扶正拧几圈确认是直的，再慢慢加力。斜着拧一定会把导向柱顶裂。全程手拧。

合壳前确认：电机线、两只限位开关线、麦克风线都已经理出来，别被壳夹住。

阶段 3

## 主机 · 总装

14

### 承载底板装进托盘

M2×5 盘头自攻 × 4，位置 (−82, ±27) 和 (+26, ±27)。

长度不可超 5mm

支撑柱底孔只有 3.4mm 深，再长就把托盘 2mm 的地板顶穿了。

板子 −X 两角是 45°×7 倒角（不是方缺口），正好让开底座的角螺柱，净距 0.89mm。放不进去说明放反了方向。

15

### 电池放进电池仓

103450 锂电（成品 51 × 34 × 10）卧放在 +X 半场，引线朝 −X，从挡边上方跨过去接 J4。

顶面离上盖还有 7mm，垫一块 EVA 泡棉压住，否则晃动时会拽引线。

16

### 上盖：先放按键帽，再拧闸体

顺序卡点 · 两件都必须在扣盖之前做

① 两个按键帽从上盖背面放进去——帽子的 φ12 法兰卡在背面沉孔里防脱，扣上盖之后就塞不进去了。

② 闸体用 M2×10 沉头自攻 × 4 从盖板背面往上拧，位置 (36.5, ±15) 和 (66.5, ±15)。扣盖之后螺丝刀伸不进去。

闸体朝向：闸杆沿 +Y 伸出，转轴靠近底座无充电口那一端。装反了充电口会被闸体挡住。

17

### 穿线、接端子

闸体来的线（电机 2 根、限位 4 根、麦克风 5 根）穿过上盖的走线孔，位置 (68, 0)，正在电池上方。

接到板上：J1 电机 / J2 限位 / J3 麦克风。飞线贴着电池顶面往 −X 走，用一点热熔胶固定，别让它垂在转动件附近。

18

### 扣上盖

M2×12 沉头自攻 × 4，位置 (±87, ±32)，底座四角。

扣之前最后确认

两个按键帽在位、闸体已拧好、所有线接好且不会被止口环压住、电池泡棉垫好。

19

### 装闸杆

闸杆 A 插进转毂夹臂（插入深度 20mm），M2×10 盘头自攻 横穿夹紧，距杆根 6mm。

整机唯一的主受力螺丝

闸杆全部重量和电机扭矩都从这颗过。手拧到发紧即可，绝对不能用电动批——会直接把 φ1.7 底孔撕开。长度不可超 10mm，否则会顶到闸体外壁，闸杆一转就刮壳。

闸杆 A/B 对接用 M2×6 盘头自攻，啮合只有 2.1mm，加一滴 502 双保险，别反复拆。

转毂 −X 配重仓从端面滑入 1~2 颗 M5 碳钢螺母（别买不锈钢，密度低），点一滴热熔胶固定。

阶段 4

## 遥控器

板 57 × 33，外壳 63 × 40 × 26。电池在板子底下，装配顺序和主机不一样。

20

### 焊接

- 先矮后高：C1（0805，已在第 1 步焊完） → 排母 → 拨动开关 → 三颗轻触开关
- U2 TP4056 贴板直焊，Type-C 朝 −X；同样先试插充电线
- U1 ESP32-C3 SuperMini 插低背 5.0 排母，不直焊——要能拔下来烧录

电池引线用 P1 那两个焊盘，不装排针

P1 是按 1×2 排针封装做的焊盘，电池线直接焊上去。不能用 KF128 端子——它高 9.5mm，而板面以上只有 6.9mm。

21

### 电池贴到板子底面

锂电 32 × 20 × 4.6 卧放在下壳电池仓（−X 半场，三面挡边），不要压在天线正下方。

22

### 板子放进下壳

四根锁紧螺柱穿过板边的四个缺口，板子坐在螺柱的 φ6 承托肩上（顶面 z = 7.1）。

这块板没有安装孔——横向靠四根柱子卡在缺口里定位，向下靠承托肩托住，向上靠上盖的四条压条压住。三者缺一板子就会窜。

23

### 上盖：放两个按键帽，扣壳

只有两个帽，不是三个

上盖只开抬杆和落杆两个孔——三个按钮对这个年龄段容易误操作。SW3 复位开关仍焊在板上，只是上盖那块是实心面板按不到。复位功能没丢：主机的离线语音本来就有「复位」这条命令。

按键帽从背面放入，然后 M2×12 沉头自攻 × 4 扣壳。扣的时候上盖背面那四条压条会正好压在板面上。

阶段检验

扣好后轻轻晃动整机，板子不应有任何哐当声。有声音说明压条没压实，检查是不是有打印毛刺垫住了。

阶段 5

## 首次上电与调试

24

### 充电测试

两台都先关拨动开关再插充电线。观察上盖／上壳观察窗里的 TP4056 指示灯：充电中红灯、充满蓝／绿灯。

两个 Type-C 别插错

遥控器上只有 U2 那个充电口是开孔的，U1 模块的 Type-C 故意不开孔——两个口都通到电池，插错会拿 5V 直接怼电芯。要烧录就拆壳把模块拔下来，排母就是为此装的。

25

### 起落杆行程与限位

上电后手动触发一次起杆、一次落杆，确认：

- 闸杆在 0°（水平） 和 90°（竖直） 干脆停住，不会撞机械止挡后继续憋着
- 停住的瞬间对应的限位开关已经动作（不是靠超时停的）
- 抬到竖直时，转毂配重端离上盖还有约 4mm，不该有摩擦声

停位不对就回阶段 2 第 11 步重新调开关位置——长圆孔留了 ±1.5mm 就是为这个。

26

### 语音与遥控

三条离线命令：起杆 / 落杆 / 复位。遥控器两个键：抬杆 / 落杆。

一按遥控器就重启？

ESP-NOW 发射瞬间电流会跳到上百 mA，供电路径上串着电池引线、拨动开关、排针，都有寄生电感。先检查 C1 有没有焊好、拨动开关触点是否可靠、电池引线是不是太细太长。

附录 A

## 螺丝速查

合计 27 颗，全部是自攻螺丝（塑件专用 PT／PA／KA 型），不是机牙螺丝——塑件里没有预埋螺母。沉头一律 90° 锥角，美制 82° 会坐不平。

规格 | 数量 | 用在哪 | 要点
M2×12 沉头 | 8 | 底座上盖 ×4、遥控器上盖 ×4 | 底座位置 (±87, ±32)
M2×10 沉头 | 4 | 闸体固定到上盖 | 必须在扣盖之前拧；(36.5, ±15) (66.5, ±15)
M2×30 沉头 | 4 | 闸体左右壳对拧 | 先手扶正，斜拧必裂导向柱
M2×10 盘头 | 5 | 微动开关 ×4、转毂夹闸杆 ×1 | 夹闸杆那颗是主受力，不可超 10mm
M2×8 盘头 | 1 | 凸轮顶丝 | 必须点螺纹胶，从前面板 φ3 孔拧
M2×6 盘头 | 1 | 闸杆 A／B 对接 | 啮合仅 2.1mm，加一滴 502
M2×5 盘头 | 4 | 承载底板固定 | 不可超 5mm，会顶穿地板
M5 六角螺母 | 1~2 | 转毂配重 | 碳钢镀锌，别买不锈钢

紧固件清单 v1.3 有几处已过期

那份文档对应 CAD v3.0。以下按本手册为准：闸体固定点 (55±15,±15) → (51.5±15,±15)；承载底板 −X 两角 不是 5×5 方缺口，是 45°×7 倒角；遥控器上盖螺柱位置与高度已随外壳改版全部变更。

附录 B

## 打印件

#### 转毂 hub · 凸轮 cam

建议树脂或 PETG，100% 填充。转毂是唯一受力件，闸杆重量和电机扭矩全从它过。

#### 按键帽 btn_cap ×2 rc_btn_cap ×2

建议树脂。需要 0.3mm 级的滑动配合精度，FDM 打不出来。

#### 壳体 6 件

base_tray / base_top / house_l / house_r / rc_bottom / rc_top。FDM 即可。

#### 闸杆 bar_a · bar_b

分两段是为了缩短打印尺寸，装配时插榫对接。

打印后先清孔

所有 φ1.7 自攻底孔、电机隧道、φ8.5 轴颈孔，打完先用钻头或美工刀清一遍残留和毛刺。电机推不进去、螺丝拧不动，十有八九是毛刺不是尺寸。

螺柱外径只有 φ4.4（M2 自攻的下限）。若打印材料偏脆、第一次拧就沿层间裂开，把 daozha.scad 的 BOSS_OD 改成 5.0 重新导出，四周都有余量。

本手册对应 cad/daozha.scad v3.3。尺寸的唯一事实源是 道闸玩具_元器件尺寸基准_v1.md；结构约束见 道闸玩具_底板机械约束_v1.md。 若手册与代码不一致，以代码和自检用例为准——那 90 多条布尔自检是唯一被机器验过的部分。

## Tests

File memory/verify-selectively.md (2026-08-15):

---
name: verify-selectively
description: 用户要求：别在低价值动作上烧 token，改完只验受影响的部分，不要无脑跑全流程
metadata:
  node_type: memory
  type: feedback
---

用户 2026-08-15 明确提出：**token 额度有限，不要在意义不大的事情上耗精力；改完东西要知道重点验哪里，不要无脑跑所有流程。**

**Why**：这个项目的自检套件跑满一轮约 25 分钟、几十次渲染。我在只改了电机隧道内壁（加压筋）之后又去跑全量 62 条——而那条隧道里除了电机没有任何别的零件，能受影响的只有 4 条用例，其余全是纯浪费。同理还有：一次性重导全部 STL、把每个中间结论都写进文档。

**How to apply**：
- 改完先问"这个改动的作用域是什么"，只跑**几何上可能相交**的那几条用例；全量套件留给"要提交/要打样"这种收口时刻。
- 后台任务不要随手开一堆，它们会互相抢 CPU，还会让我反复轮询浪费轮次。
- 报告只给结论和关键数字，推导过程除非用户问否则不铺开。
- ⚠ 但**阳性对照不能省** —— 那是防止"检测失效了都不知道"的，属于高价值动作，见 [[daozha-toy-scope]] 的教训清单。省的是范围，不是严谨度。

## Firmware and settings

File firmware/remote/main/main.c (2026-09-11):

// 道闸玩具 · 遥控器固件（ESP32-C3 SuperMini）
//
// 全流程：被按键从深睡唤醒 -> 按着期间持续发 JOG -> 松手发 STOP -> 接着睡。
// 不建常驻任务，醒着的时间越短越好 —— 电池只有 250mAh，
// 而且没有电量检测（100k/100k 分压静态就 18.5µA，把深睡预算全吃了）。
//
// 2026-09-11 起是「长按走、松手停」（主机那边限位装不准，改由人盯着）。
// JOG 是保活包：主机 GATE_JOG_DEADMAN_MS 内收不到下一个就自己停，
// 所以遥控器掉线 / 走出范围 / 没电，杆子都不会一直转。
#include "board.h"
#include "gate_proto.h"

#include <string.h>

#include "driver/gpio.h"
#include "esp_log.h"
#include "esp_mac.h"
#include "esp_now.h"
#include "esp_sleep.h"
#include "esp_timer.h"
#include "esp_wifi.h"
#include "freertos/FreeRTOS.h"
#include "freertos/task.h"
#include "nvs.h"
#include "nvs_flash.h"

static const char *TAG = "rc";
static const char *NVS_NS = "rc";
static const char *NVS_KEY_PEER = "gate_mac";
static const char *NVS_KEY_SEQ = "seq";

static const uint8_t BCAST[ESP_NOW_ETH_ALEN] = { 0xFF, 0xFF, 0xFF, 0xFF, 0xFF, 0xFF };

static uint8_t s_gate[ESP_NOW_ETH_ALEN];
static bool s_have_gate;
static volatile bool s_acked;

/* ---------- NVS ---------- */

/* seq 只在醒来时读一次、睡前写一次。JOG 每 100ms 一包，要是每包都写 NVS，
 * 一次长按就是几十次 flash 写 —— 会把 flash 写穿。
 * 醒来先跳 SEQ_LEAP，保证就算上次没来得及写回（比如电池拔了），这次的 seq 也比上次大。 */
#define SEQ_LEAP 1000
static uint32_t s_seq;

static void seq_load(void)
{
    nvs_handle_t h;
    if (nvs_open(NVS_NS, NVS_READONLY, &h) == ESP_OK) {
        nvs_get_u32(h, NVS_KEY_SEQ, &s_seq);
        nvs_close(h);
    }
    s_seq += SEQ_LEAP;
}

static void seq_save(void)
{
    nvs_handle_t h;
    if (nvs_open(NVS_NS, NVS_READWRITE, &h) == ESP_OK) {
        nvs_set_u32(h, NVS_KEY_SEQ, s_seq);
        nvs_commit(h);
        nvs_close(h);
    }
}

static uint32_t seq_next(void) { return ++s_seq; }

static void gate_load(void)
{
    nvs_handle_t h;
    if (nvs_open(NVS_NS, NVS_READONLY, &h) != ESP_OK) return;
    size_t len = ESP_NOW_ETH_ALEN;
    s_have_gate = (nvs_get_blob(h, NVS_KEY_PEER, s_gate, &len) == ESP_OK && len == ESP_NOW_ETH_ALEN);
    nvs_close(h);
}

static void gate_save(const uint8_t *mac)
{
    memcpy(s_gate, mac, ESP_NOW_ETH_ALEN);
    s_have_gate = true;
    nvs_handle_t h;
    if (nvs_open(NVS_NS, NVS_READWRITE, &h) == ESP_OK) {
        nvs_set_blob(h, NVS_KEY_PEER, mac, ESP_NOW_ETH_ALEN);
        nvs_commit(h);
        nvs_close(h);
    }
    ESP_LOGI(TAG, "记住主机 " MACSTR, MAC2STR(mac));
}

/* ---------- 按键 ---------- */

static void buttons_init(void)
{
    gpio_config_t cfg = {
        .pin_bit_mask = BTN_WAKE_MASK,
        .mode = GPIO_MODE_INPUT,
        .pull_up_en = GPIO_PULLUP_ENABLE,
    };
    gpio_config(&cfg);
}

static bool pressed(gpio_num_t pin)
{
    return gpio_get_level(pin) == BTN_ACTIVE_LEVEL;
}

static bool any_pressed(void)
{
    return pressed(PIN_BTN_UP) || pressed(PIN_BTN_DN) || pressed(PIN_BTN_RST);
}

/* ---------- ESP-NOW ---------- */

static void on_recv(const esp_now_recv_info_t *info, const uint8_t *data, int len)
{
    gate_pkt_t pkt;
    if (len != (int)sizeof(pkt)) return;
    memcpy(&pkt, data, sizeof(pkt));
    if (!gate_pkt_valid(&pkt, sizeof(pkt))) return;
    if (pkt.cmd != GATE_CMD_ACK) return;

    if (!s_have_gate || memcmp(info->src_addr, s_gate, ESP_NOW_ETH_ALEN) != 0) {
        gate_save(info->src_addr);
    }
    s_acked = true;
    ESP_LOGI(TAG, "收到 ACK，主机状态=%u", pkt.arg);
}

static void peer_add(const uint8_t *mac)
{
    esp_now_peer_info_t p = { .channel = GATE_ESPNOW_CHAN, .ifidx = WIFI_IF_STA, .encrypt = false };
    memcpy(p.peer_addr, mac, ESP_NOW_ETH_ALEN);
    if (!esp_now_is_peer_exist(mac)) esp_now_add_peer(&p);
}

static void radio_up(void)
{
    ESP_ERROR_CHECK(esp_netif_init());
    ESP_ERROR_CHECK(esp_event_loop_create_default());
    wifi_init_config_t wcfg = WIFI_INIT_CONFIG_DEFAULT();
    ESP_ERROR_CHECK(esp_wifi_init(&wcfg));
    ESP_ERROR_CHECK(esp_wifi_set_storage(WIFI_STORAGE_RAM));   /* 别写 flash，省时间也省寿命 */
    ESP_ERROR_CHECK(esp_wifi_set_mode(WIFI_MODE_STA));
    ESP_ERROR_CHECK(esp_wifi_start());
    ESP_ERROR_CHECK(esp_wifi_set_channel(GATE_ESPNOW_CHAN, WIFI_SECOND_CHAN_NONE));

    ESP_ERROR_CHECK(esp_now_init());
    ESP_ERROR_CHECK(esp_now_register_recv_cb(on_recv));

    peer_add(BCAST);
    if (s_have_gate) peer_add(s_gate);
}

static void send_cmd(uint8_t cmd, bool force_broadcast)
{
    const uint8_t *dst = (s_have_gate && !force_broadcast) ? s_gate : BCAST;
    gate_pkt_t pkt = { .cmd = cmd, .seq = seq_next(), .arg = 0 };
    gate_pkt_seal(&pkt);

    for (int i = 0; i < SEND_REPEAT && !s_acked; i++) {
        esp_now_send(dst, (const uint8_t *)&pkt, sizeof(pkt));
        vTaskDelay(pdMS_TO_TICKS(SEND_GAP_MS));
    }
    for (int w = 0; w < ACK_WAIT_MS / 10 && !s_acked; w++) {
        vTaskDelay(pdMS_TO_TICKS(10));
    }
    ESP_LOGI(TAG, "cmd=%u seq=%lu -> " MACSTR " %s",
             cmd, (unsigned long)pkt.seq, MAC2STR(dst), s_acked ? "已确认" : "无应答");
}

/* 发一包就走，不重发不等 ACK。JOG 用：丢了下一包 100ms 后就到 */
static void send_one(uint8_t cmd)
{
    const uint8_t *dst = s_have_gate ? s_gate : BCAST;
    gate_pkt_t pkt = { .cmd = cmd, .seq = seq_next(), .arg = 0 };
    gate_pkt_seal(&pkt);
    esp_now_send(dst, (const uint8_t *)&pkt, sizeof(pkt));
}

/* 长按走：按着就每 GATE_JOG_PERIOD_MS 发一个 JOG，松手（或另一个键也按下、或按太久）就发 STOP */
static void jog_until_release(gpio_num_t pin, uint8_t jog_cmd)
{
    int64_t t0 = esp_timer_get_time();
    int n = 0;
    while (pressed(pin)) {
        if (pressed(PIN_BTN_UP) && pressed(PIN_BTN_DN)) break;   /* 两个都按着 = 意图不明 */
        if (esp_timer_get_time() - t0 > JOG_HOLD_MAX_MS * 1000LL) {
            ESP_LOGW(TAG, "按住超过 %d ms，当卡键处理", JOG_HOLD_MAX_MS);
            break;
        }
        send_one(jog_cmd);
        n++;
        vTaskDelay(pdMS_TO_TICKS(GATE_JOG_PERIOD_MS));
    }
    /* STOP 连发几次：主机有看门狗兜底，但 STOP 到得越早手感越跟手 */
    s_acked = false;
    send_cmd(GATE_CMD_STOP, false);
    ESP_LOGI(TAG, "cmd=%u 共发 %d 个 JOG，按了 %lld ms", jog_cmd, n,
             (long long)((esp_timer_get_time() - t0) / 1000));
}

/* ---------- 睡 ---------- */

static void go_sleep(void)
{
    seq_save();
    /* 等所有键松开再睡，否则按住不放会被立刻唤醒、循环发命令 */
    int64_t t0 = esp_timer_get_time();
    while (any_pressed() && (esp_timer_get_time() - t0) < RELEASE_TIMEOUT_MS * 1000LL) {
        vTaskDelay(pdMS_TO_TICKS(20));
    }

    esp_now_deinit();
    esp_wifi_stop();

    /* ⚠ C3 没有 RTC IO（`SOC_RTCIO_PIN_COUNT == 0`），`rtc_gpio_*` 那套函数在这颗芯片上
     *   根本不存在 —— 不用（也不能）手工去开 RTC 上拉。
     *   深睡期间的上拉由 `ESP_SLEEP_GPIO_ENABLE_INTERNAL_RESISTORS`（默认开）在
     *   `esp_deep_sleep_start()` 里按唤醒模式自动配：低电平唤醒 -> 自动上拉。
     *   板上也确实没有外部上拉（设计方案 §4.2：三个键统一按下接 GND，用内部上拉）。
     *   静态不耗电，只有按下的瞬间流 3.3V/45k ≈ 73µA，对 <20µA 的深睡指标没影响。 */
    ESP_ERROR_CHECK(esp_sleep_enable_gpio_wakeup_on_hp_periph_powerdown(
        BTN_WAKE_MASK, ESP_GPIO_WAKEUP_GPIO_LOW));

    ESP_LOGI(TAG, "睡了");
    esp_deep_sleep_start();
}

/* ---------- 主流程 ---------- */

void app_main(void)
{
    esp_err_t err = nvs_flash_init();
    if (err == ESP_ERR_NVS_NO_FREE_PAGES || err == ESP_ERR_NVS_NEW_VERSION_FOUND) {
        ESP_ERROR_CHECK(nvs_flash_erase());
        err = nvs_flash_init();
    }
    ESP_ERROR_CHECK(err);

    buttons_init();
    gate_load();
    seq_load();

    vTaskDelay(pdMS_TO_TICKS(DEBOUNCE_MS));   /* 消抖：唤醒瞬间电平还在弹 */

    bool up = pressed(PIN_BTN_UP);
    bool dn = pressed(PIN_BTN_DN);
    bool rst = pressed(PIN_BTN_RST);
    /* 原始电平。内部上拉，没按应该都是 1。开机就读到 0 = 硬件把它拉低了
     * （轻触开关焊到内部相通的那对脚上是最常见的原因） */
    ESP_LOGI(TAG, "键电平 抬(GPIO%d)=%d 落(GPIO%d)=%d 复位(GPIO%d)=%d，0=按下",
             PIN_BTN_UP, gpio_get_level(PIN_BTN_UP),
             PIN_BTN_DN, gpio_get_level(PIN_BTN_DN),
             PIN_BTN_RST, gpio_get_level(PIN_BTN_RST));

    if (!up && !dn && !rst) {
        /* 噪声唤醒或已松手，什么都别发 */
        ESP_LOGI(TAG, "无按键，回去睡");
        go_sleep();
    }

    radio_up();

    if (up && dn) {
        /* 抬杆+落杆同时按住 3s = 配对。用这两个键是因为
         * 复位键在上盖背面按不到（面板是实心的）*/
        int64_t t0 = esp_timer_get_time();
        while (pressed(PIN_BTN_UP) && pressed(PIN_BTN_DN)) {
            if (esp_timer_get_time() - t0 >= PAIR_HOLD_MS * 1000LL) {
                ESP_LOGI(TAG, "发配对广播（主机需在开机 60s 内）");
                send_cmd(GATE_CMD_PAIR, true);
                go_sleep();
            }
            vTaskDelay(pdMS_TO_TICKS(20));
        }
        /* 没按满 3s 就松了一个 —— 意图不明，不猜，直接睡 */
        ESP_LOGI(TAG, "双键未按满 3s，放弃");
        go_sleep();
    }

    if (up)       jog_until_release(PIN_BTN_UP, GATE_CMD_JOG_UP);
    else if (dn)  jog_until_release(PIN_BTN_DN, GATE_CMD_JOG_DN);
    else if (rst) send_cmd(GATE_CMD_RESET, false);

    go_sleep();
}

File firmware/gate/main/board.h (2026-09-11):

// 主机（ESP32-S3-DevKitC-1 N16R8）引脚与电气常数
// 唯一事实源：../../../道闸玩具_底板网表基准_v2.md §3、设计方案 v2 §4.1
// ⚠ 改这里之前先改网表文档，不许在代码里自定义引脚。
#pragma once

#include "driver/gpio.h"

/* ---- 麦克风 INMP441，I2S0（M5 语音才用）---- N20/N21/N22 */
#define PIN_MIC_SCK      GPIO_NUM_4
#define PIN_MIC_WS       GPIO_NUM_5
#define PIN_MIC_SD       GPIO_NUM_6

/* ---- 电机 DRV8833 ---- N9/N10/N11 */
#define PIN_M_AIN1       GPIO_NUM_9
#define PIN_M_AIN2       GPIO_NUM_10
#define PIN_M_SLEEP      GPIO_NUM_11   /* 高=工作。模块内部下拉 -> 上电默认休眠 */

/* ---- 限位微动 ---- N16/N17。内部上拉 + 常闭(NC)接法，公共端到 J2.1(GND)
 * 未压合 = NC 闭合 = 读到 0；压到位 = NC 断开 = 读到 1。
 * 断线也读 1（=到位）-> 电机停，失效方向是安全的。
 * ⚠ 接线：J2 第 2 脚接【落杆】限位、第 3 脚接【起杆】限位（PCB 定稿时对调过，
 *   见 底板机械约束 §七之三）。GPIO 侧不受影响。 */
#define PIN_LIMIT_UP     GPIO_NUM_12   /* 抬到位 90° */
#define PIN_LIMIT_DN     GPIO_NUM_13   /* 落到位 0°  */
#define LIMIT_ACTIVE_LEVEL   1

/* ---- 按键 ---- N18/N19。按下接 GND，内部上拉 */
#define PIN_BTN_UP       GPIO_NUM_17
#define PIN_BTN_DN       GPIO_NUM_18
#define BTN_ACTIVE_LEVEL     0

/* ---- 有源蜂鸣器 ---- N23：GPIO -> R5 -> Q1(S8050 NPN) -> LS1。高=响 */
#define PIN_BUZZER       GPIO_NUM_2

/* ---- 电池采样 ---- N15：VBAT --100k--+--100k-- GND，中点进 ADC1_CH0 */
#define PIN_VBAT_DIV     GPIO_NUM_1
#define VBAT_DIV_RATIO   2.0f          /* 100k/100k */

/* ================= 电机标定 =================
 * 🔴 MOTOR_INVERT 在 M1 阶段（USB 供电、手动点动）实测确定：
 *    先按 0 烧进去，按抬杆键看闸杆是不是往上走；反了就改成 1 重烧。
 *    电机引线焊反、或转毂装到另一侧，都会翻转。别猜。 */
#define MOTOR_INVERT     0

/* PWM。20kHz 以下电机啸叫刺耳（方案 §7.3）。
 * 11 bit 分辨率上限 80MHz/2048 = 39kHz，20kHz 有余量 */
#define MOTOR_PWM_HZ         20000
#define MOTOR_PWM_RES_BITS   11
#define MOTOR_DUTY_MAX       ((1 << MOTOR_PWM_RES_BITS) - 1)

/* 占空比档位（百分比）*/
#define DUTY_RUN         85    /* 正常行程 */
#define DUTY_SOFT_START  40    /* 软启动起点，200ms 线性升到 DUTY_RUN */

#define SOFT_START_MS    200
#define BRAKE_MS         300   /* AIN1=AIN2=高 刹车，之后拉低 nSLEEP */

/* ================= 走多久 =================
 * 🔴 2026-09-11 起控制模型改成「长按走、松手停」：
 *    限位开关装不到精确位置，所以它不再是动作的依据，只是「碰到就停」的加分项。
 *    走多远由操作的人盯着，固件只兜底：
 *      JOG_MAX_MS      —— 按住不放的上限。抬杆侧有机械止挡，按住 = 电机堵转发热
 *      JOG_DEADMAN_MS  —— 多久没收到「还在按着」就停。底座键 50ms 投一次、遥控 100ms 发一次
 *      TIMED_TRAVEL_MS —— 语音「起杆/落杆」没法长按，就走这么久。
 *                         初值取自 2026-09-10 那轮标定收敛到的 T=2243ms
 * 原来那套 T 标定 / 1.15T 防砸 / 1.5T 超时 / 0.85T 缓停 全部作废：
 * 没有可靠限位就量不出 T，量不出 T 那些系数就没有参照物。防砸是**有意放弃**的。 */
#define JOG_MAX_MS          5000
#define JOG_DEADMAN_MS       300
#define TIMED_TRAVEL_MS     2200

#define MOTION_TICK_MS       5      /* 状态机轮询周期，也是限位采样周期 */

/* 双键同时长按 3s = 复位（方案 §7.1）*/
#define BTN_DEBOUNCE_MS      20
#define BTN_RESET_HOLD_MS    3000

/* 开机后这段时间内受理遥控器配对广播 */
#define PAIR_WINDOW_MS       60000

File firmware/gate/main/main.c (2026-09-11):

// 道闸玩具 · 主机固件入口
// 方案：../../../道闸玩具_电路与结构设计方案_v2.md §7
#include "board.h"
#include "buzzer.h"
#include "comms.h"
#include "events.h"
#include "input.h"
#include "motion.h"
#include "sr.h"

#include "esp_log.h"
#include "freertos/FreeRTOS.h"
#include "freertos/task.h"
#include "nvs_flash.h"

static const char *TAG = "main";

QueueHandle_t g_evt_q;

void evt_post(evt_type_t type, evt_src_t src, uint16_t arg)
{
    evt_t e = { .type = (uint8_t)type, .src = (uint8_t)src, .arg = arg };
    if (g_evt_q && xQueueSend(g_evt_q, &e, 0) != pdTRUE) {
        ESP_LOGW(TAG, "事件队列满，丢弃 type=%d", type);
    }
}

void app_main(void)
{
    esp_err_t err = nvs_flash_init();
    if (err == ESP_ERR_NVS_NO_FREE_PAGES || err == ESP_ERR_NVS_NEW_VERSION_FOUND) {
        ESP_ERROR_CHECK(nvs_flash_erase());
        err = nvs_flash_init();
    }
    ESP_ERROR_CHECK(err);

    g_evt_q = xQueueCreate(8, sizeof(evt_t));

    buzzer_init();
    motion_start();   /* 内部自动 HOMING */
    input_start();
    comms_start();
    sr_start();

    ESP_LOGI(TAG, "启动完成");

    for (;;) {
        vTaskDelay(pdMS_TO_TICKS(5000));
        ESP_LOGI(TAG, "状态=%s VBAT=%.2fV",
                 motion_state_name(motion_state()), input_battery_v());
    }
}

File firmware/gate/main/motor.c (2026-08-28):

#include "motor.h"

#include "board.h"
#include "driver/ledc.h"
#include "esp_log.h"
#include "freertos/FreeRTOS.h"
#include "freertos/task.h"

static const char *TAG = "motor";

#define LEDC_MODE     LEDC_LOW_SPEED_MODE
#define CH_AIN1       LEDC_CHANNEL_0
#define CH_AIN2       LEDC_CHANNEL_1
#define TIMER_SEL     LEDC_TIMER_0

static uint32_t pct_to_duty(uint8_t pct)
{
    if (pct > 100) pct = 100;
    return (uint32_t)MOTOR_DUTY_MAX * pct / 100u;
}

static void set_ch(ledc_channel_t ch, uint32_t duty)
{
    ledc_set_duty(LEDC_MODE, ch, duty);
    ledc_update_duty(LEDC_MODE, ch);
}

void motor_init(void)
{
    gpio_config_t slp = {
        .pin_bit_mask = 1ULL << PIN_M_SLEEP,
        .mode = GPIO_MODE_OUTPUT,
    };
    gpio_config(&slp);
    gpio_set_level(PIN_M_SLEEP, 0);   /* 先保证休眠，再配 PWM */

    ledc_timer_config_t tcfg = {
        .speed_mode      = LEDC_MODE,
        .timer_num       = TIMER_SEL,
        .duty_resolution = MOTOR_PWM_RES_BITS,
        .freq_hz         = MOTOR_PWM_HZ,
        .clk_cfg         = LEDC_AUTO_CLK,
    };
    ESP_ERROR_CHECK(ledc_timer_config(&tcfg));

    const gpio_num_t pins[2] = { PIN_M_AIN1, PIN_M_AIN2 };
    const ledc_channel_t chs[2] = { CH_AIN1, CH_AIN2 };
    for (int i = 0; i < 2; i++) {
        ledc_channel_config_t ccfg = {
            .gpio_num   = pins[i],
            .speed_mode = LEDC_MODE,
            .channel    = chs[i],
            .timer_sel  = TIMER_SEL,
            .duty       = 0,
            .hpoint     = 0,
        };
        ESP_ERROR_CHECK(ledc_channel_config(&ccfg));
    }
    ESP_LOGI(TAG, "PWM %d Hz / %d bit, MOTOR_INVERT=%d", MOTOR_PWM_HZ, MOTOR_PWM_RES_BITS, MOTOR_INVERT);
}

void motor_drive(motor_dir_t dir, uint8_t duty_pct)
{
    if (dir == MOTOR_STOP || duty_pct == 0) {
        set_ch(CH_AIN1, 0);
        set_ch(CH_AIN2, 0);
        return;
    }

    gpio_set_level(PIN_M_SLEEP, 1);

    /* 单脚 PWM + 另一脚拉低 = 快衰减。MOTOR_INVERT 只在这一处生效 */
    bool up = (dir == MOTOR_UP);
#if MOTOR_INVERT
    up = !up;
#endif
    uint32_t duty = pct_to_duty(duty_pct);
    set_ch(up ? CH_AIN1 : CH_AIN2, duty);
    set_ch(up ? CH_AIN2 : CH_AIN1, 0);
}

void motor_brake(void)
{
    gpio_set_level(PIN_M_SLEEP, 1);
    set_ch(CH_AIN1, MOTOR_DUTY_MAX);
    set_ch(CH_AIN2, MOTOR_DUTY_MAX);
}

void motor_stop_and_sleep(void)
{
    motor_brake();
    vTaskDelay(pdMS_TO_TICKS(BRAKE_MS));
    set_ch(CH_AIN1, 0);
    set_ch(CH_AIN2, 0);
    gpio_set_level(PIN_M_SLEEP, 0);
}

void motor_kill(void)
{
    set_ch(CH_AIN1, 0);
    set_ch(CH_AIN2, 0);
    gpio_set_level(PIN_M_SLEEP, 0);
}

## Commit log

2026-08-11 手册提交
    [bar_a.stl, bar_b.stl, base_top.stl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]
2026-08-11 cad 升级
    [bar_a.stl, bar_b.stl, base_top.stl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]
2026-08-12 CAD v2.6: 修复机械止挡、N20 电机座与 D 形轴孔
    三处都是"看着对、实际不成立"的几何问题:
    1. 机械止挡把闸杆卡死在 35~40°, 根本到不了 90°
    挡块侧面距转轴 3.5mm, 而转臂侧面在 7mm, 挡块整个埋在转臂的扫掠
    包络里 —— 摆在 100° 那条射线上没用, 转臂比它宽, 早就先扫到。
    改用扫掠差集生成: 毛坯 − 转臂 0..STOP_ANG 扫过的区域, 差集边界
    恰好是转臂在 STOP_ANG 时的轮廓, 位置由几何自己算出。
    注意相邻角度实例必须取 hull() 填缝: 靠近转臂尖端回转半径时角度
    覆盖收窄到 1.7°, 5° 步长会漏出细缝, 长成提前挡路的毛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
    [bar_a.stl, bar_b.stl, base_top.stl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]
2026-08-12 文档规整: 建立元器件尺寸基准, CAD 冻结在 v2.6
    改变工作方式: 先定元件尺寸, 再动 3D。
    起因是 v2.2~v2.6 连续四轮修的装配硬伤根因是同一类 —— 拿没核实的
    元件尺寸/形状去建模, 再从结构里倒推 (N20 按圆柱建、排母漏算 2.5mm
    隔片、止挡块按角度摆、D 孔画成并集)。
    新增《元器件尺寸基准 v1》作为所有物理尺寸的唯一事实源:
    · CAD 不允许自己定义元件尺寸, 只能引用它
    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
2026-08-12 修复 README 编码, 清理过程文件, 同步防砸方案变更
    1. README.md 编码修复
    上次改写时沿用了原文件的 UTF-16LE 编码却没写 BOM 头, 编辑器认不出
    来 (file 报 "data")。内容完好, 已转成 UTF-8, 与其余文档一致。
    2. 删除过时的过程文件 (git 历史里仍可追回)
    · 道闸玩具_底板网表基准_v1.md 被 v2 取代
    · cad/daozha_cad_v2.2.zip v2.2 时代的快照, 现已 v2.6
    · cad/cut.scad v2.2 时代肉眼看剖面的辅助脚本,
    已被 check.scad 的布尔交集判定取代
    · cad/png/ 删 16 张旧渲染, 只留 6 张当前有效的
    3. 同步网表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
    [cut.scad]
2026-08-12 基准表: 按尺寸图填入 N20 实测数据
    更正此前"N20 机身没有安装孔"的错误说法 —— 那是 Pololu micro
    metal gearmotor 的情况, 本项目这款减速箱端面有 2xM1.6 深 2.1 螺孔,
    可以从"合壳摩擦夹紧"升级为螺丝硬固定。
    从卖家尺寸图确读并填入 (来源标 📄):
    截面 10(X) x 12(Z)
    减速箱 9 + 电机 15 + 尾盖 1.2 = 机身总长 25.2 (CAD 现值 26)
    输出轴 φ3 公差 0/-0.03, 伸出 10 (CAD 现值 9)
    轴根凸台 φ4 凸出 0.7 (CAD 里还没有这个特征)
    端面 2xM1.6 深 2.1
    轴长 9->10 会让轴比孔底深 0.5mm 顶死, 孔深是由 MOT_Y0 - SHAFT_L
    反推的, 改参数即自动修正。
    图纸未标注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
2026-08-12 基准表: 填入 N20 的 D 面对边 2.45mm
    实物标注图给出 φ3 配 2.45 —— D 轴的标准标注对(直径 + 对边)。
    推出: 平面距轴心 0.95, 切深 0.55, D 面弦宽 2.32。
    CAD 现用假设值 2.5 (平面距轴心 1.0), 差 0.05mm。
    N20 至此除 2xM1.6 孔位坐标外全部转 📄。孔位不阻塞设计 ——
    矩形隧道夹紧方案已验证可用, 端面螺丝固定属可选升级, 优先级从
    三星降为一星。
2026-08-12 基准表: 记录 M1.6 孔对称性, 说明坐标仍欠一个数
    用户确认两孔关于端面中心对称。但对称只给出一个方程、两个未知数:
    x^2+y^2=20.25 的可行区间跨度约 2mm, 而 M1.6 过孔需要 ±0.3mm 定位
    精度, 不够用。
    另有一层不确定: 两张图里的"9"都可能是减速箱长度而非孔距。
    只需再补一个数(两孔的水平或垂直间距任一个)即可闭合。不阻塞设计。
2026-08-12 限位开关定为带簧片杠杆型, 并暴露 SW_HOLE_R 与托板的约束冲突
    设计方案原写"短柄无杠杆", 这是错的 —— 行程量级差 6 倍:
    凸轮升程(基圆 r6 -> 凸起 r9) = 3.0mm
    无杠杆直动柱塞总行程 = 约 0.5mm
    直动式吸收不了 3mm, 会被凸轮压毁。杠杆还提供超行程顺应性(吸收打印
    公差、转毂间隙、凸轮偏心)和安装位置容差。不选滚轮型, 省 4mm 高度。
    连带算出一处新冲突: SW_HOLE_R=12.5 时开关本体内缘在 r=7.4, 会撞
    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
2026-08-12 限位开关定型 MG1-R10P40, 并推出凸轮与托板的改动
    从 MG1 规格书填入: 本体 12.8x6.55x5.8, 安装孔 φ2.2 间距 6.5,
    插脚 3x0.9 脚距 5.08 长 3.5, FP10.4/OP8.8, 六款的行程与操作力。
    选型:
    排除 1 号无杆 —— 行程只有 0.3mm, 吸收不了凸轮升程
    排除 6 号滚轮 —— 多占高度, 低速小力用不上, 空间不允许
    选 4 号 R10P40 圆弧10mm —— 圆弧尖端是凸面, 滑过上升沿是骑上去;
    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
2026-08-12 限位开关改选 ZIPPY DF-PIS-1E-M-Z
    与 MG1 是同一种标准小型微动开关的不同品牌, 本体和安装孔几乎完全
    一样(12.7~12.8 x 6.55~6.60 x 5.80, 孔距 6.5, 孔径 φ2.2), 结构上
    可互换。改选的决定性因素是端子形式:
    限位开关装在闸体托板上, 用飞线接到底板 J2, 不是焊在 PCB 上。
    MG1 是直插脚(PCB 针), 3.5mm 细针上挂飞线根部容易疲劳断;
    ZIPPY 是焊线脚(带孔焊片), 线穿过去再焊, 这才是限位开关的标准接法。
    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
2026-08-12 按键定为 6x6x12 + 新增打印按键帽
    规格书明确: 总高 12 = 底座 3.5 + 开关柄 8.5 (不含引脚), 行程 0.25mm,
    THT 4 脚脚距 4.5, 动作力 70~300gf 是系列范围。
    设计方案原写的 6x6x5 差了 8.4mm。但 12mm 也不够 —— 差 1.4mm:
    v2.5 为塞下低背排母把 BASE_H 从 20 加到 22, 天花板从 17 抬到 19,
    原本刚好探出 0.6mm 的 12mm 顶杆就够不到了。这是加高底座的连带代价。
    结论: 6x6x12 + 打印按键帽。理由不只是补高度 —— 顶杆只有 φ3.5,
    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
2026-08-12 按键帽改为露出盖面 2.5mm, 按压面加大到 φ8.5
    第一版让帽顶与盖面齐平, 等于没有按键 —— 手指摸不到边界, 也没有
    按下去的行程感。是我保守了。
    新方案:
    上盖通孔 φ6.5 -> φ9
    上盖背面 新增 φ12.5 x 深1.5 沉孔 (导向 + 挡法兰)
    按键帽 法兰 φ12x2.7 (z17.8~20.5) + 柄 φ8.5x4.0 (z20.5~24.5)
    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
2026-08-12 拨动开关定为 SK12D07VG7 (卧式侧拨两档)
    方向问题解决: 原选型 SS12D00G3 拨柄朝上, 装板上指天, 与前端面开口
    方向对不上; SK12D07VG7 是卧式侧拨, 拨柄平行 PCB 面伸出, 正对前端面。
    读图填入: 本体 8.7x4.4, 含引脚总高 7.2~7.3, 信号脚 3 个间距 2.0
    (0/2/4) 两端另有固定脚总跨 8.3, 脚厚 0.4/0.5, 拨柄宽 2 行程 2,
    拨柄高 H 系列 2~12 可选。
    高度对位良好: 本体占 z 5.6~10.0, 前端面开口 z 6~10, 基本重合,
    开口不用改。
    H 可选 2~12 是个可利用的自由度 —— 按"拨柄尖停在 x=-76(外壁外露
    1mm)"反推: H=7 对应本体前面缩在板边内 2mm, 可用。
    🔴 引脚间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
2026-08-14 修正文档内容
2026-08-15 CAD 解冻到 v3.0；遥控器原理图建成并校验
    CAD (12 项积压改动一次做完，12 个零件):
    - 底座 183x73x25 / 承载底板 120x65，元件全部按 PCB 定稿坐标
    - 转毂拆成 hub + cam (一整件穿不过 φ8.5 壁孔)，壁孔内侧加 φ12x4 轴承凸台
    - 凸轮升程 3.3 + 两端 18° 过渡斜坡；开关托板拆成两块安装台 + 径向长圆孔
    - 新增打印件 cam、btn_cap x2；麦克风圆窝 + 压舌
    - 新增爆炸图视图 (p=13，EXP 系数可扫出装配动画)
    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
    [bar_a.stl, bar_b.stl, base_top.stl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]
2026-08-15 充电口按插头塑料头开、拨柄外移达标、安装孔让开螺丝头、电机加压筋
    主机 PCB（未下单，趁还能改）
    - SW3 -82.6 → -84.1：拨柄外露 0.51 → 2.01mm，达到尺寸基准 §366 的 1mm 判据。
    原值是按老底座（外壁面 -75）算的，底座放大到 183 后没回头重算。物料已买齐，
    换不了拨柄高度 H，所以在板上补回来。
    - VBAT_SW 拐角 -80 → -78.5：安装孔 (-82,27) 孔心到非 GND 铜箔 1.50 → 3.00mm。
    M2 盘头 φ3.5~4.0 原来会同时压住 VBAT_SW 和 GND 覆铜，只隔一层阻焊 = 电池短路。
    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
    [bar_a.stl, bar_b.stl, base_top.stl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]
2026-08-15 充电灯观察孔按实物改到 (-80, 0)
    原 (-84,-6) 是按「指示灯紧邻 Type-C 座」的常见排布猜的，用户按实物给了准确位置。
    顺带切掉的止口环从 6.25mm 减到 2.25mm。README 的待确认项划掉。
    [base_top.stl, daozha.scad]
2026-08-15 遥控器上盖补充电指示灯观察窗
    外壳坐标 (-18.7, 2.0)，窗 6x4。位置由主机那颗实测值反推：同款 28x17 模块、
    同为 rot 0，LED 相对模块中心 (-5.2, +6)，套到 U2 (PCB -13.5,-5.5) 得
    PCB (-18.7, 0.5) = 外壳 (-18.7, 2.0)。
    窗只能 6x4 不能照抄主机的 10x6：SW1 的 phi11.5 按键导向凸台在外壳 (-16,10.5)，
    窗放大或往 +Y 挪会啃进凸台，导向跨度变短按键会晃。现让开 0.76mm。
    自检 t=90/91，阳性对照用最初拟的 (-18,5)，必须啃上凸台。
    [check.scad, daozha.scad, rc_top.stl]
2026-08-15 闸杆方向从 +X 改成 +Y：闸体绕 Z 转 90 度
    原来闸杆顺着底座长边伸出，整机在 X 上拉到 183+300=483mm，而且不是道闸的样子
    （真道闸是机箱蹲在路边、杆子横跨路面）。
    改得动是因为两件事凑巧：
    - 闸体平面是 46x46 正方形，转 90 度占位不变，不会新压住按键
    - 上盖四个闸体固定孔 HS_BOSS=[[±15,±15]] 是正方形阵列、90 度映射到自身，
    上盖的孔一个都不用动（t=3/4 验过）
    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
    [base_top.stl, check.scad, daozha.scad]
2026-08-15 遥控器上盖只保留抬杆/落杆两个按键孔
    三个按钮对 6~10 岁的孩子容易误操作。SW3 复位开关仍焊在板上、PCB 一点没动，
    只是上盖那块变成实心面板按不到。复位功能不丢：主机离线语音本来就有这条命令。
    拆成两张表是有意的：
    - RC_BTN_CAP_POS（两颗）管开孔、沉孔、导向凸台、按键帽
    - RC_BTN_POS（三颗）管开关本体净空 —— t=70 必须仍按三颗全查，SW3 头顶
    从通孔变成实心料，更要确认让得开（顶面 17.7，盖背 23，余 5.3）
    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
    [check.scad, daozha.scad, rc_top.stl]
2026-08-15 转毂配重端削 3mm 让开上盖；全部 STL 重导；闸杆角度做成参数
    HUB_ARM_X0 -16 -> -13。抬杆到 90 度时配重端正指向下，落点 z = 42-16 = 26，
    而上盖顶面 25，只剩 1mm，打印公差加面板下挠就会擦。削到 -13 后净距 4.0mm。
    配重力矩掉 25%，但本来就只有闸杆力矩的 0.6%（M5 螺母 1.6g/力臂 9mm
    对闸杆 15g/力臂 150mm），可忽略。
    止挡块是 stop_blank() 减去闸杆扫掠体生成的，臂一短止挡跟着变大，
    所以验了 t=34/35（限位角没变）和 t=16。
    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
    [bar_a.stl, bar_b.stl, base_top.stl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]
2026-08-15 遥控器上盖加四条板压条：板子原来只被托住、没被压住
    原结构: 四根柱子 phi6 承托肩(顶面 7.1)托住板底, phi4.4 上段穿板边缺口做横向定位,
    但往上什么都没有。板面 8.7、上盖内表面 23，板子能窜到 U1 叠高顶(20.4)撞盖为止 = 2.6mm。
    后果不只是响: 板一抬，开关本体跟着抬，顶杆把按键帽顶到法兰坐死，再抬就是误触发。
    四条压条从上盖背面伸到板面(14.3mm)，每条贴着一个承托肩正上方——压点正对支点，
    板子不受弯。用条不用柱: +Y 边只有 y 12..15 这 3mm 空当，圆柱最大 phi3 且余量为零。
    PCB 一个孔都不用加。
    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
    [check.scad, daozha.scad, rc_top.stl]
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2026-08-16 添加3D打印文件
    [daozha.3mf]
2026-08-28 编写固件
    [partitions.csv]
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2026-09-10 删掉开机回零：位置未知不需要靠转电机来消除
    原设计上电自动 HOMING（慢速走到落位限位）。实机暴露三个问题：
    - 凸轮相位或开关位置差一点，就变成一开机 FAULT 长鸣、整机不可用
    - 拨开关瞬间杆子自己动，对 6~10 岁玩家是惊吓
    - 回零往落杆方向走，而机械止挡只做在抬杆侧，落杆侧开关一失效就只剩超时一道
    关键认识：每条命令本来就是「往这个方向走到限位为止」，不需要知道起点。
    所以开机停在 UNKNOWN、不动、两个方向都放行，第一条命令自己就把状态定下来。
    - ST_BOOT/ST_HOMING 合并成 ST_UNKNOWN；只有 FAULT 拒绝命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
    [board.h, motion.c]
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
